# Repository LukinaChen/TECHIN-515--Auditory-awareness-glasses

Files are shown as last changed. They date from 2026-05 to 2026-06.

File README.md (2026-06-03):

# Auditory Awareness Glasses

Real-time wearable assistive glasses for deaf and hard-of-hearing users. The system detects, classifies, and localizes environmental sounds, then alerts the wearer through NeoPixel LEDs (visual) and haptic vibration motors (tactile) built into the glasses frame.

## Team

- **Lukina Chen** — Hardware lead, TDOA signal processing, PCB design (rear boards + main board)
- **Anuj Kamasamudram** — ML & software lead, YAMNet sound classification, front board PCB design
- **Yilu Huang** — Signal & firmware lead, GPIO alert dispatch timing, main board v2 design

## System Architecture

```
4× T5838 PDM Mics ──→ TXS0108 Level Shifter ──→ XIAO ESP32-S3
    (1.8V)              (1.8V ↔ 3.3V)              (3.3V)
                                                       │
                                    ┌──────────────────┤
                                    ▼                  ▼
                              3× NeoPixel LED    2× ERM Motor
                              (direction)        (rear alert)
```

All processing runs on-device with no internet connection. The ESP32-S3 captures audio from four PDM microphones, runs a quantized YAMNet model for sound classification, and uses TDOA (Time Difference of Arrival) across mic pairs for direction estimation.

| Layer | Technology |
|---|---|
| Sound classification | YAMNet (Google, 521 AudioSet classes), int8 quantized |
| Edge hardware | XIAO ESP32-S3 (8 MB flash + 8 MB PSRAM) |
| Microphones | 4× T5838 (MMICT5838-00-012) PDM MEMS, 1.8V |
| Visual output | 3× SK6812-MINI-E NeoPixel LEDs |
| Haptic output | 2× ERM coin vibration motors |
| Level shifting | TXS0108EPWR (TSSOP-20), 1.8V ↔ 3.3V |
| Power | LiPo battery → Xiao charger → XC6206P182MR-G 1.8V LDO |

## Sound → Alert Mapping

| Sound Category | LED Color | Motor |
|---|---|---|
| Silence | OFF | Off |
| Speech / Voice | Blue | Off |
| Music | Purple | Off |
| Alarm / Siren | Red | Both vibrate |
| Animal sounds | Yellow | Off |
| Door / Knock | Orange | Off |
| Horn / Beeping | Orange | Rear vibrate |
| Vehicle | White | Rear vibrate |
| Phone ringing | Purple | Off |
| Other | Green | Off |

LED color encodes the sound category. Motor vibration triggers only for rear-origin sounds, alerting the user to threats they cannot see.

## Direction Estimation (TDOA)

Four microphones are arranged in two pairs to estimate direction:

- **Front pair** (PCB1): 2× T5838 on the glasses front frame — left/right discrimination
- **Rear pair** (PCB5 or PCB2/3): 2× T5838 near the ears — front/back discrimination

The ESP32-S3 runs two I2S PDM interfaces. Cross-correlation between mic pairs yields a time delay that maps to an angle of arrival. Results from the TDOA test rig (breadboard prototype):

| Direction | Accuracy |
|---|---|
| Left / Right | 7/7 = 100% |
| Front | 3/3 = 100% |
| Back | 2/5 = 40% (breadboard contact issues) |

## Hardware: PCB Design

The system uses multiple PCBs connected by 0.5 mm pitch FPC cables.

### PCB1 — Front Board (Anuj)

Sits on the top of the glasses front frame (~60 mm long).

- 2× T5838 mic, 3× SK6812-MINI-E LED, XC6206 LDO, caps, WAKE combining diodes
- Connects to main board via 2× FH12 6-pin FPC

### PCB2 & PCB3 — Rear Boards (Lukina)

Sit at the ends of the glasses arms near the ears (~25 mm each). Same schematic, mirrored.

- 1× T5838 mic, 1× ERM motor, SI2302 MOSFET, 1N4148W diode, ferrite bead, 2× 100nF caps
- PCB2 mic SELECT → GND (left channel), PCB3 mic SELECT → 1V8 (right channel)
- Connects to main board via FH12 8-pin FPC
- Layout rule: mic at one end, motor at the other, separate GND pours with single-point join

### PCB4 — Main Board v1 (Lukina)

Central hub at the back of the head. Houses the MCU, level shifter, LDO, and all FPC connectors.

- U1: Xiao ESP32-S3 SMD, U2: XC6206 1.8V LDO, U3: TXS0108EPWR level shifter
- 4× FPC connectors (2× 6-pin for front board, 2× 8-pin for rear boards)
- JST PH 2-pin battery connector, PCM12SMTR SPDT switch
- Top side: Xiao + switch + battery connector. Bottom side: everything else.

### PCB5 — Main Board v2 (Yilu)

Combines PCB2, PCB3, and PCB4 into a single board. Rear mics and motor driver are integrated on-board. Connects to front board only via 2× 6-pin FPC.

Components: Xiao ESP32-S3 SMD, XC6206 LDO, TXS0108EPWR, 2× T5838 (MK3/MK4), SI2302 + 1N4148W motor driver, PCM12SMTR switch, JST PH battery connector.

## Firmware

### PlatformIO Configuration

```ini
[env:seeed_xiao_esp32s3]
platform = espressif32
board = seeed_xiao_esp32s3
framework = arduino
monitor_speed = 115200
build_flags = -DARDUINO_USB_CDC_ON_BOOT=1
```

### GPIO Pin Map (PCB5)

| GPIO | Xiao Pin | Function |
|---|---|---|
| GPIO1 | D0 | PDM_CLK (all mics clock) |
| GPIO2 | D1 | PDM_DATA (rear mics, through TXS0108) |
| GPIO3 | D2 | WAKE_JST_3V3 |
| GPIO4 | D3 | PDM_THSEL |
| GPIO5 | D4 | MTR_PWM (ERM motor via MOSFET) |
| GPIO6 | D5 | PDM_DATA_FRONT (front mics) |
| GPIO43 | D6 | LED_DATA (NeoPixel) |
| GPIO9 | Pin 11 | WAKE_M4_3V3 |

### I2S PDM Channel Mapping

ESP32-S3 I2S swaps left/right relative to the T5838 convention:

```cpp
// samples[i]   = Right channel (MK3, SELECT=1V8)
// samples[i+1] = Left channel  (MK4, SELECT=GND)
```

### Basic Mic Test Code

```cpp
#include <Arduino.h>
#include <driver/i2s.h>

#define I2S_WS   1   // PDM_CLK
#define I2S_DIN  2   // PDM_DATA
#define SAMPLE_RATE 16000
#define BUFFER_SIZE 512

int16_t samples[BUFFER_SIZE];

void setup() {
    Serial.begin(115200);
    delay(2000);

    i2s_config_t i2s_config = {
        .mode = (i2s_mode_t)(I2S_MODE_MASTER | I2S_MODE_RX | I2S_MODE_PDM),
        .sample_rate = SAMPLE_RATE,
        .bits_per_sample = I2S_BITS_PER_SAMPLE_16BIT,
        .channel_format = I2S_CHANNEL_FMT_RIGHT_LEFT,
        .communication_format = I2S_COMM_FORMAT_STAND_I2S,
        .intr_alloc_flags = ESP_INTR_FLAG_LEVEL1,
        .dma_buf_count = 4,
        .dma_buf_len = BUFFER_SIZE,
    };

    i2s_pin_config_t pin_config = {
        .bck_io_num = I2S_PIN_NO_CHANGE,
        .ws_io_num = I2S_WS,
        .data_out_num = I2S_PIN_NO_CHANGE,
        .data_in_num = I2S_DIN,
    };

    i2s_driver_install(I2S_NUM_0, &i2s_config, 0, NULL);
    i2s_set_pin(I2S_NUM_0, &pin_config);
}

void loop() {
    size_t bytes_read;
    i2s_read(I2S_NUM_0, samples, sizeof(samples), &bytes_read, portMAX_DELAY);

    int num = bytes_read / sizeof(int16_t);
    int16_t min_l = 32767, max_l = -32768;
    int16_t min_r = 32767, max_r = -32768;

    for (int i = 0; i < num; i += 2) {
        if (samples[i] > max_r) max_r = samples[i];
        if (samples[i] < min_r) min_r = samples[i];
        if (samples[i+1] > max_l) max_l = samples[i+1];
        if (samples[i+1] < min_l) min_l = samples[i+1];
    }

    Serial.printf("L[%d,%d] Range:%d | R[%d,%d] Range:%d\n",
                  min_l, max_l, max_l - min_l,
                  min_r, max_r, max_r - min_r);
    delay(200);
}
```

Expected signal levels:

| State | Range |
|---|---|
| Quiet room | 5,000 – 15,000 |
| Normal speech | 30,000 – 65,535 |
| Loud clap | 50,000 – 65,535 |
| Data line disconnected | Fixed at -30,935 |

## ML Pipeline (Laptop Prototyping)

The ML pipeline runs on a laptop for prototyping. In production, the quantized model runs directly on the ESP32-S3.

### Repository Layout

```
DetectionGlasses/
└── YamnetTest/
    ├── yamnet_mic_test.py            # Live mic classification (no hardware)
    ├── yamnet_esp32_feasibility.py   # TFLite conversion + ESP32 feasibility report
    ├── yamnet_serial.py              # Laptop → USB serial → XIAO NeoPixel bridge
    ├── yamnet_accuracy_test.py       # float32 vs int8 accuracy on ESC-50
    ├── yamnet_urbansound_test.py     # Accuracy on UrbanSound8K
    ├── neopixel_noise_test/
    │   └── neopixel_noise_test.ino   # Arduino NeoPixel LED control sketch
    └── tflite_models/
        ├── yamnet_full.tflite        # ~3.7 MB float32
        ├── yamnet_int8.tflite        # ~0.9 MB int8 quantized (ESP32 target)
        └── yamnet_saved_model/
```

### Quick Start

```bash
# Live mic demo (laptop only, no hardware)
pip install tensorflow tensorflow-hub sounddevice numpy scipy
python YamnetTest/yamnet_mic_test.py

# Generate TFLite models + ESP32 feasibility report
pip install tensorflow tensorflow-hub numpy
python YamnetTest/yamnet_esp32_feasibility.py

# Serial bridge (laptop mic → USB → XIAO NeoPixels)
pip install tensorflow tensorflow-hub sounddevice numpy pyserial
python YamnetTest/yamnet_serial.py --port /dev/cu.usbmodem1101

# Accuracy benchmarks
pip install tensorflow tensorflow-hub numpy scipy soundfile librosa tqdm
python YamnetTest/yamnet_accuracy_test.py --esc50-dir YamnetTest/downloads/ESC-50-master
python YamnetTest/yamnet_urbansound_test.py --limit 200
```

### Serial Protocol

```
C:speech:0.92:180    # category, confidence, brightness (0-255)
B:180                # brightness-only update
T:0.50               # set confidence threshold
OFF                  # turn LEDs off
```

### ESP32-S3 Model Feasibility

| Resource | Requirement | ESP32-S3 (N8R8) | Status |
|---|---|---|---|
| Flash | ~0.9 MB (int8) | 8 MB | ✅ |
| RAM (activations) | ~300–400 KB | 8 MB PSRAM | ✅ |
| Inference time | ~200 ms target | TBD | — |

## Known Issues

- **TXS0108 OE wiring bug (PCB5):** R1 was routed to 3V3 instead of 1V8. OE max is VCCA+0.5V = 2.3V. Fixed with fly wire. Must be corrected in next revision.
- **MK3 weak signal (PCB5):** Right-channel mic produces very low Range (~100 vs expected ~10,000). Likely a soldering defect. Needs resolder or replacement.
- **FPC intermittent contact (PCB3):** Data line drops to fixed -30,935 value. Caused by loose FPC cable or connector lock. Resolved by reinserting and locking FPC.
- **ESP32 USB boot issue:** After uploading certain code, USB CDC may fail to initialize. Fix: double-click RESET to enter bootloader, then immediately upload.

## Bill of Materials

| Component | Part Number | Qty | Notes |
|---|---|-----|---|
| MCU | XIAO ESP32-S3 SMD | 1 | Castellated pads |
| Microphone | MMICT5838-00-012 (T5838) | 4 | PDM MEMS, 1.8V |
| Level shifter | TXS0108EPWR | 1 | TSSOP-20, 1.8V ↔ 3.3V |
| 1.8V LDO | XC6206P182MR-G | 1 | SOT-23 |
| NeoPixel LED | SK6812-MINI-E | 3 | RGB addressable |
| ERM motor | 10mm coin type | 2 | Vibration haptic |
| MOSFET | SI2302 | 1–2 | SOT-23, motor switch |
| Flyback diode | 1N4148W | 1–2 | SOD-323 |
| Ferrite bead | 600Ω 0402 | 1–2 | Motor power filtering |
| FPC connector (6-pin) | FH12-6S-0.5SH | 2–4 | Front board connection |
| FPC connector (8-pin) | FH12-8S-0.5SH | 2 | Rear board connection |
| Battery connector | JST PH 2-pin | 1 | LiPo battery |
| Switch | PCM12SMTR | 1 | SPDT SMD |
| Battery | LiPo 500–1000 mAh | 1 | 3.7V nominal |

## GitHub

[https://github.com/LukinaChen/TECHIN-515--Auditory-awareness-glasses](https://github.com/LukinaChen/TECHIN-515--Auditory-awareness-glasses)

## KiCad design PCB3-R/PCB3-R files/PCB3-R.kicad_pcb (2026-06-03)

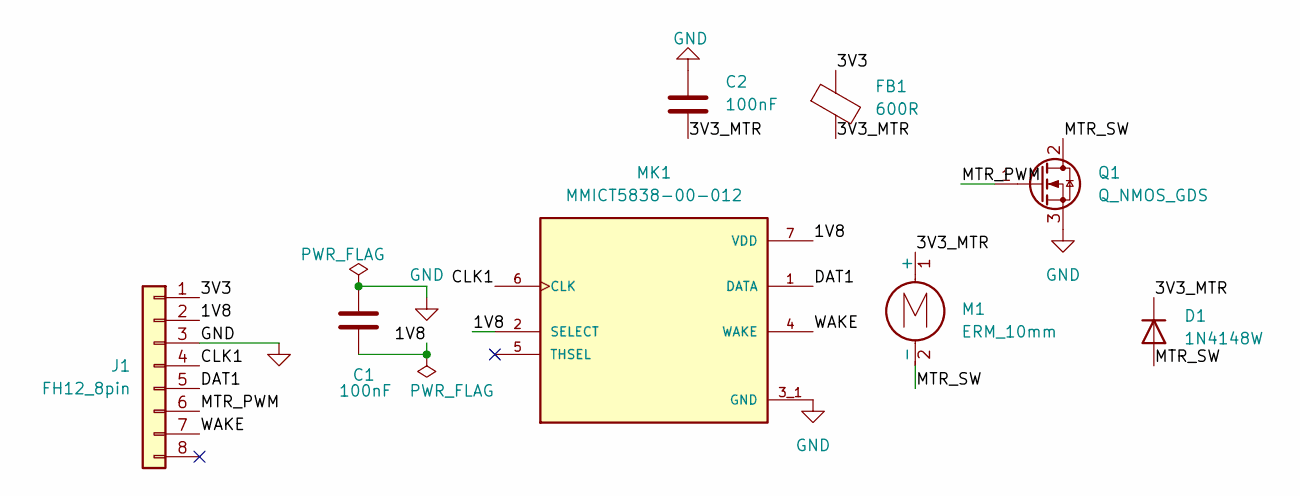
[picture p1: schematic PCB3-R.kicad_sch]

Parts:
C1, C2: 100nF; C_0402_1005Metric
D1: 1N4148W; D_SOD-323
FB1: 600R; L_0402_1005Metric
J1: FH12_8pin; Hirose_FH12-8S-0.5SH_1x08-1MP_P0.50mm_Horizontal
M1: ERM_10mm; PinHeader_1x02_P2.54mm_Vertical
MK1: MMICT5838-00-012; MIC_MMICT5838-00-012; PARTREV 1.1
Q1: Q_NMOS_GDS; SOT-23

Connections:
/1V8: C1.2, J1.2, MK1.2 (SELECT), MK1.7 (VDD)
/3V3: FB1.1, J1.1
/3V3_MTR: C2.2, D1.1 (K), FB1.2, M1.1 (+)
/CLK1: J1.4, MK1.6 (CLK)
/DAT1: J1.5, MK1.1 (DATA)
/MTR_PWM: J1.6, Q1.1 (G)
/MTR_SW: D1.2 (A), M1.2 (-), Q1.2 (D)
/WAKE: J1.7, MK1.4 (WAKE)
GND: C1.1, C2.1, J1.3, MK1.3_1 (GND), MK1.3_2 (GND), Q1.3 (S)

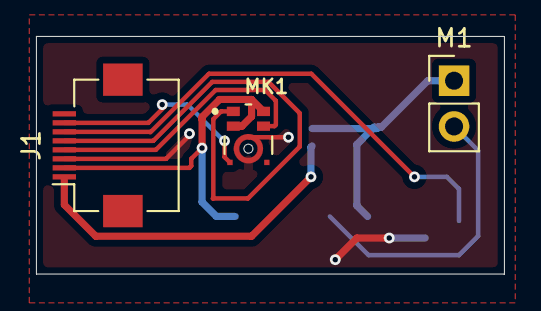
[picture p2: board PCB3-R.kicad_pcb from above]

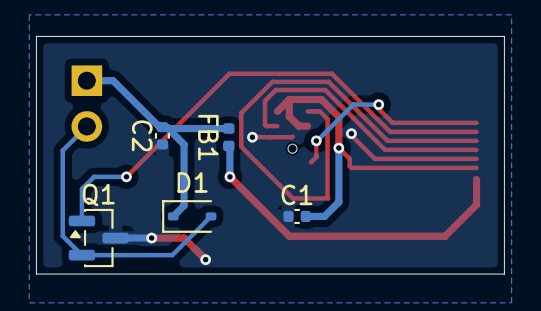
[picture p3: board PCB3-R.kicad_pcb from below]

Board: 2 copper layers, 26.0 x 13.2 mm, 8 parts (5 on the bottom side), 9 nets.

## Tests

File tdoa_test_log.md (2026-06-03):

# Project Handoff Summary — Auditory Awareness Glasses (Updated)

## Project Overview
Wearable assistive glasses for deaf/hard-of-hearing users. Detects, classifies, and localizes environmental sounds in real time. Alerts user through LED bar (visual) and haptic vibration motors (tactile) built into glasses frame.

---

## Team & Roles
- **Lukina Chen (you)** — Hardware lead, TDOA signal processing, PCB design for rear boards + main board
- **Anuj Kamasamudram** — ML & software lead, YAMNet sound classification, PCB1 (front board) design
- **Yilu Huang** — Signal & firmware lead, GPIO alert dispatch timing, designed PCB5 (main board v2)

---

## System Architecture
- **MCU:** Xiao ESP32-S3 (SMD version)
- **Mics:** 4× T5838 (MMICT5838-00-012) PDM MEMS microphones, 1.8V supply
- **Output:** 3× SK6812-MINI-E NeoPixel LEDs + 2× ERM coin motors
- **Power:** LiPo battery → Xiao (built-in charger + 3.3V LDO) → XC6206P182MR-G (1.8V LDO for mics)
- **Level shifter:** TXS0108EPWR (TSSOP-20) — 1.8V ↔ 3.3V conversion for all mic signals
- **No internet connection** — all processing on-device

---

## PCB Status Summary

### PCB2 & PCB3 (Rear Boards - Lukina's design)
- Schematic: ✅ Done
- PCB layout: ✅ Done
- DRC: ✅ Pass
- Gerber: ✅ Exported
- **PCB3 (Right) Testing:**
  - Mic: ✅ Confirmed working (tested with breakout board + ESP32-S3 on breadboard)
  - ERM motor: ✅ Confirmed working (controlled via MOSFET, GPIO must be pulled LOW to stop motor)
  - FPC connection: ⚠️ Intermittent contact issues (34601 fixed value when FPC disconnects)

### PCB4 (Main Board - Lukina's design)
- Schematic: ✅ Done
- PCB layout: ✅ Done
- DRC status:
  - 1 excluded error: B.Cu GND zone missing connection (ignorable — GND pads connected via F.Cu)
  - Remaining warnings: silkscreen clipping (ignorable)
  - Dangling track warnings: cleaned up (PDM_DAT1, MTR_PWM_R, 1V8, PDM_CLK1_1V8)
- Mounting holes: ✅ Added (4× MountingHole_2.1mm at corners)
- Board outline: ✅ Fixed (Edge.Cuts gap closed)
- **Not yet fabricated or assembled**

### PCB5 (Main Board v2 - Yilu's design, combines PCB2/3 + main)
- Schematic: ✅ Done
- PCB fabricated: ✅ Done
- Components soldered: ✅ Done
- **Testing results:**
  - Power: ✅ 3.3V and 1.8V confirmed correct
  - TXS0108 level shifter: ✅ Working (after OE fix)
  - MK4 mic (SELECT=GND, Left channel): ✅ Working — Range ~10000 quiet, 50000+ clap
  - MK3 mic (SELECT=1V8, Right channel): ❌ Very weak signal — Range ~100 quiet, ~5000 speaking
  - ERM motor: Not yet tested on PCB5
  - Front PCB connection: Not yet tested

### PCB1 (Front Board - Anuj's design)
- Not yet tested with main board

---

## Critical Bugs Found & Fixed

### 1. TXS0108 OE voltage error (PCB5)
- **Problem:** R1 (11kΩ) connected OE to 3V3 instead of 1V8
- **Impact:** OE max voltage is VCCA+0.5V = 2.3V, 3.3V exceeded limit
- **Fix:** Removed R1, flew wire from OE (Pin 10) to LDO VOUT (1.8V) with R1 in series
- **Status:** ✅ Fixed, OE now reads 1.8V

### 2. TXS0108 Pin 18 virtual solder (PCB5)
- **Problem:** Pin 18 (PDM_DATA B-side) had cold solder joint, ESP32 D1 read 0.2V instead of ~1.5V
- **Impact:** Neither MK3 nor MK4 data could reach ESP32
- **Fix:** Re-soldered Pin 18
- **Status:** ✅ Fixed, MK4 now works

### 3. MK3 weak signal (PCB5)
- **Problem:** MK3 Range only ~100 (should be ~10000), very weak response to sound
- **Likely cause:** MK3 soldering issue (VDD or DATA pad)
- **Status:** ❌ Unresolved — MK3 was removed for standalone testing, needs to be soldered back or replaced

---

## ESP32 I2S PDM Important Notes

### Channel swap
ESP32 I2S channels are swapped from T5838 convention:
- `samples[i]` = **Right channel** (MK3, SELECT=1V8)
- `samples[i+1]` = **Left channel** (MK4, SELECT=GND)

### Working I2S configuration (PCB5)
```cpp
#define I2S_WS   1   // PDM_CLK → GPIO1 (D0)
#define I2S_DIN  2   // PDM_DATA → GPIO2 (D1)

i2s_config_t i2s_config = {
    .mode = (i2s_mode_t)(I2S_MODE_MASTER | I2S_MODE_RX | I2S_MODE_PDM),
    .sample_rate = 16000,
    .bits_per_sample = I2S_BITS_PER_SAMPLE_16BIT,
    .channel_format = I2S_CHANNEL_FMT_RIGHT_LEFT,
};
```

### T5838 supply voltage
- Design voltage: 1.8V (for power saving and TXS0108 compatibility)
- Testing: Works at 3.3V (VDD range 1.6V–3.6V), but noise floor is higher
- PCB3 standalone testing used 3.3V on both VDD and 1V8 pins

### Signal levels (normal operation)
| State | Expected Range |
|---|---|
| Quiet | 5000–15000 |
| Speaking | 30000–65535 |
| Clap | 50000–65535 |

### Common failure mode
- `-30935` fixed value = **data line disconnected** (FPC contact, virtual solder, or mic not present)

---

## PCB5 GPIO Pin Assignment (Yilu's design)

| GPIO | Xiao Pin | Function |
|---|---|---|
| GPIO1 | D0 | PDM_CLK (all mics clock) |
| GPIO2 | D1 | PDM_DATA (rear mics data, through TXS0108) |
| GPIO3 | D2 | WAKE_JST_3V3 |
| GPIO4 | D3 | PDM_THSEL |
| GPIO5 | D4 | MTR_PWM (ERM motor via MOSFET) |
| GPIO6 | D5 | PDM_DATA_FRONT (front mics data) |
| GPIO43 | D6 | LED_DATA (NeoPixel) |
| GPIO9 | Pin 11 | WAKE_M4_3V3 |

## TXS0108 Pin Map (PCB5)

| Physical Pin | Function | Side |
|---|---|---|
| 1 | CLK net (A1) | 1.8V |
| 2 | VCCA (+1V8) | Power |
| 3 | DATA_BACK net (A2) | 1.8V |
| 4 | DATA_FRONT net (A3) | 1.8V |
| 5 | WAKE_JST_1V8 (A4) | 1.8V |
| 6 | THSEL net (A5) | 1.8V |
| 7 | WAKE_M4_1V8 (A6) | 1.8V |
| 8 | GND (A7) | — |
| 9 | GND (A8) | — |
| 10 | OE | Enable (→1V8 via R1) |
| 11 | GND | — |
| 12 | GND | — |
| 13 | GND (B7) | — |
| 14 | WAKE_M4_3V3 (B6) | 3.3V |
| 15 | PDM_THSEL (B5) | 3.3V |
| 16 | WAKE_JST_3V3 (B4) | 3.3V |
| 17 | PDM_DATA_FRONT (B3) | 3.3V |
| 18 | PDM_DATA (B2) | 3.3V |
| 19 | VCCB (Net-U1-3V3) | Power |
| 20 | PDM_CLK (B1) | 3.3V |

---

## PCB5 BOM

| Reference | Qty | Value | Footprint |
|---|-----|---|---|
| Batteryconnector1 | 1 | S2B-PH-K-SLFSN | JST PH 2-pin |
| C1,C6,C7 | 3 | 2.2μF | 0603 |
| C2,C3,C4,C5,C8,C9 | 6 | 680nF | 0603 |
| D1 | 1 | Diode | SOD-123 |
| FB1 | 1 | Ferrite Bead | 0402 |
| J1_Right1 | 1 | FPC 6-pin (Right) | FH12-6S-0.5SH |
| J2_Left1 | 1 | FPC 6-pin (Left) | FH12-6S-0.5SH |
| J3 | 1 | ERM coin motor | Pin Header 2-pin |
| MK3, MK4 | 2 | MMICT5838-00-012 | T5838 |
| Q1 | 1 | SI2302 | SOT-23 |
| R1 | 1 | 11kΩ | 0603 |
| SW2 | 1 | PCM12SMTR | SPDT SMD |
| U1 | 1 | XIAO-ESP32-S3-SMD | Castellated SMD |
| U2 | 1 | XC6206P182MR-G | SOT-23 (1.8V LDO) |
| U3 | 1 | TXS0108EPWR | TSSOP-20 |

---

## FPC Connector Pin Definitions (PCB5)

### J2_Left1 (6-pin, to front board)
1. DATA_FRONT net
2. CLK net
3. THSEL net
4. WAKE_JST_1V8
5. NC
6. NC

### J1_Right1 (6-pin, to front board)
1. NC
2. +1V8
3. GND
4. LED_DATA
5. NC
6. NC

---

## What Needs to Be Done Next

1. ❌ Fix MK3 on PCB5 — resolder or replace with new T5838
2. ❌ Test ERM motor on PCB5 (use Serial command 'm'/'s')
3. ❌ Test front PCB (PCB1) connected to PCB5 via FPC
4. ❌ Test LED output
5. ❌ Full system integration test (all 4 mics + LED + motor)
6. ❌ Battery power test
7. ✅ PCB4 (Lukina's main board) — DRC clean, ready for Gerber export if needed as backup

---

## Items Already Purchased
- MMICT5838-00-012 × 5
- ESP32-S3 × 2
- FH12-6S-0.5SH (6-pin) × 6
- XC6206P182MR-G × 6
- INMP441 (testing) × 8
- SPH0645 (testing) × 4
- TXS0108EPWR × 2 (1 used on PCB5, 1 spare)
- FH12-8S-0.5SH (8-pin) × 5
- FPC cable 8-pin 0.5mm × 3
- FPC cable 6-pin 0.5mm × 3
- SI2302 MOSFET SOT-23 × 4
- 1N4148W SOD-323 × 4
- Ferrite bead 600Ω 0402 × 4
- Capacitors (0402 and 0603)
- ERM coin motor 10mm × 2
- SPDT switch × 2
- JST PH 2-pin × 1
- PCM12SMTR from DigiKey

## Still Need
- LiPo battery 500-1000mAh × 1
- Replacement T5838 for MK3 (if current one is damaged)

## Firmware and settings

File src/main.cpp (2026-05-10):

/*
 * 4-Mic TDOA + Motor + LED Alert System
 * Board: Xiao ESP32-S3
 * 
 * I2S0 (front pair):
 *   SCK → GPIO7 (D8), WS → GPIO8 (D9), SD → GPIO9 (D10)
 *   Mic1 L/R → GND (front left), Mic2 L/R → 3.3V (front right)
 *
 * I2S1 (rear pair):
 *   SCK → GPIO1 (D0), WS → GPIO2 (D1), SD → GPIO3 (D2)
 *   Mic3 L/R → GND (rear left), Mic4 L/R → 3.3V (rear right)
 *
 * Motor (via S8050 NPN + 1kΩ + 1N4148):
 *   Left motor  → GPIO4 (D3)
 *   Right motor → GPIO6 (D5)
 *
 * NeoPixel LED:
 *   DIN → GPIO5 (D4), VDD → 3.3V, GND → GND
 */

#include <Arduino.h>
#include <driver/i2s.h>
#include <Adafruit_NeoPixel.h>

// ----- I2S0 Pins (front pair) -----
#define I2S0_SCK  7
#define I2S0_WS   8
#define I2S0_SD   9

// ----- I2S1 Pins (rear pair) -----
#define I2S1_SCK  1
#define I2S1_WS   2
#define I2S1_SD   3

// ----- Motor Pins -----
#define MTR_LEFT  4   // GPIO4 (D3)
#define MTR_RIGHT 6   // GPIO6 (D5)

// ----- NeoPixel LED -----
#define LED_PIN   5   // GPIO5 (D4)
#define LED_COUNT 1
Adafruit_NeoPixel led(LED_COUNT, LED_PIN, NEO_GRB + NEO_KHZ800);

// ----- Audio Settings -----
#define SAMPLE_RATE     44100
#define BUFFER_LEN      512
#define CAPTURE_SAMPLES 1200
#define MAX_DELAY       20
#define CLAP_THRESHOLD  15000
#define COOLDOWN_MS     800
#define ALERT_DURATION  500  // motor vibrate + LED on for 1 second

// ----- Buffers -----
int32_t raw_i2s0[BUFFER_LEN];
int32_t raw_i2s1[BUFFER_LEN];

int32_t front_left[CAPTURE_SAMPLES];
int32_t front_right[CAPTURE_SAMPLES];
int32_t rear_left[CAPTURE_SAMPLES];
int32_t rear_right[CAPTURE_SAMPLES];

int capture_index = 0;
bool capturing = false;
bool ready_to_analyze = false;
int trial_number = 0;
unsigned long last_trigger_time = 0;
unsigned long alert_start_time = 0;
bool alerting = false;

void setup_i2s(i2s_port_t port, int sck, int ws, int sd) {
  i2s_config_t config = {
    .mode = (i2s_mode_t)(I2S_MODE_MASTER | I2S_MODE_RX),
    .sample_rate = SAMPLE_RATE,
    .bits_per_sample = I2S_BITS_PER_SAMPLE_32BIT,
    .channel_format = I2S_CHANNEL_FMT_RIGHT_LEFT,
    .communication_format = I2S_COMM_FORMAT_STAND_I2S,
    .intr_alloc_flags = ESP_INTR_FLAG_LEVEL1,
    .dma_buf_count = 8,
    .dma_buf_len = BUFFER_LEN,
    .use_apll = false,
    .tx_desc_auto_clear = false,
    .fixed_mclk = 0
  };

  i2s_pin_config_t pins = {
    .bck_io_num   = sck,
    .ws_io_num    = ws,
    .data_out_num = I2S_PIN_NO_CHANGE,
    .data_in_num  = sd
  };

  i2s_driver_install(port, &config, 0, NULL);
  i2s_set_pin(port, &pins);
  i2s_zero_dma_buffer(port);
}

void setup() {
  Serial.begin(115200);
  delay(2000);

  // Setup motors
  pinMode(MTR_LEFT, OUTPUT);
  pinMode(MTR_RIGHT, OUTPUT);
  digitalWrite(MTR_LEFT, LOW);
  digitalWrite(MTR_RIGHT, LOW);

  // Setup NeoPixel
  led.begin();
  led.clear();
  led.show();

  // Setup I2S
  setup_i2s(I2S_NUM_0, I2S0_SCK, I2S0_WS, I2S0_SD);
  setup_i2s(I2S_NUM_1, I2S1_SCK, I2S1_WS, I2S1_SD);

  delay(500);

  Serial.println("==========================================");
  Serial.println("  4-Mic TDOA + Motor + LED Alert");
  Serial.println("  Left motor:  GPIO4 (D3)");
  Serial.println("  Right motor: GPIO6 (D5)");
  Serial.println("  NeoPixel:    GPIO5 (D4)");
  Serial.println("==========================================");
  Serial.println("Ready! Clap to test direction + alert.");
  Serial.println("------------------------------------------");
}

void remove_dc(int32_t* buf, int len) {
  int64_t sum = 0;
  for (int i = 0; i < len; i++) sum += buf[i];
  int32_t dc = sum / len;
  for (int i = 0; i < len; i++) buf[i] -= dc;
}

int compute_tdoa(int32_t* buf_a, int32_t* buf_b) {
  remove_dc(buf_a, CAPTURE_SAMPLES);
  remove_dc(buf_b, CAPTURE_SAMPLES);

  float max_corr = 0;
  int best_delay = 0;

  for (int d = -MAX_DELAY; d <= MAX_DELAY; d++) {
    float corr = 0;
    int count = 0;
    for (int i = 0; i < CAPTURE_SAMPLES; i++) {
      int j = i + d;
      if (j >= 0 && j < CAPTURE_SAMPLES) {
        corr += (float)buf_a[i] * (float)buf_b[j];
        count++;
      }
    }
    if (count > 0) corr /= count;
    if (corr > max_corr) {
      max_corr = corr;
      best_delay = d;
    }
  }
  return best_delay;
}

void trigger_alert(const char* lr_dir, const char* fr_dir) {
  // LED color based on left/right direction
  if (strcmp(lr_dir, "LEFT") == 0) {
    led.setPixelColor(0, led.Color(0, 0, 255));    // Blue = left
    Serial.println("  [LED] Blue (left)");
  } else if (strcmp(lr_dir, "RIGHT") == 0) {
    led.setPixelColor(0, led.Color(0, 255, 0));    // Green = right
    Serial.println("  [LED] Green (right)");
  } else {
    led.setPixelColor(0, led.Color(255, 255, 255)); // White = center
    Serial.println("  [LED] White (center)");
  }
  led.show();

  // Motor only vibrates for BACK sounds
  if (strcmp(fr_dir, "BACK") == 0) {
    if (strcmp(lr_dir, "LEFT") == 0) {
      digitalWrite(MTR_LEFT, HIGH);
      digitalWrite(MTR_RIGHT, LOW);
      Serial.println("  [MOTOR] Left vibrate (back-left)");
    } else if (strcmp(lr_dir, "RIGHT") == 0) {
      digitalWrite(MTR_LEFT, LOW);
      digitalWrite(MTR_RIGHT, HIGH);
      Serial.println("  [MOTOR] Right vibrate (back-right)");
    } else {
      digitalWrite(MTR_LEFT, HIGH);
      digitalWrite(MTR_RIGHT, HIGH);
      Serial.println("  [MOTOR] Both vibrate (back-center)");
    }
  } else {
    digitalWrite(MTR_LEFT, LOW);
    digitalWrite(MTR_RIGHT, LOW);
    Serial.println("  [MOTOR] Off (front/middle)");
  }

  alerting = true;
  alert_start_time = millis();
} 


void stop_alert() {
  digitalWrite(MTR_LEFT, LOW);
  digitalWrite(MTR_RIGHT, LOW);
  led.clear();
  led.show();
  alerting = false;
}

void analyze_direction() {
  // Left-Right: average of front pair AND rear pair
  int lr_delay_front = compute_tdoa(front_left, front_right);
  int lr_delay_rear = compute_tdoa(rear_left, rear_right);
  int lr_delay = (lr_delay_front + lr_delay_rear) / 2;

  // Front-Back: average of left side AND right side
  int fb_delay_left = compute_tdoa(front_left, rear_left);
  int fb_delay_right = compute_tdoa(front_right, rear_right);
  int fb_delay = (fb_delay_left + fb_delay_right) / 2;

  float lr_us = (float)lr_delay / SAMPLE_RATE * 1000000.0;
  float fb_us = (float)fb_delay / SAMPLE_RATE * 1000000.0;

  const char* lr_dir;
  if (lr_delay > 3) lr_dir = "RIGHT";
  else if (lr_delay < -3) lr_dir = "LEFT";
  else lr_dir = "CENTER";

  const char* fr_dir;
if (fb_delay > 5) fr_dir = "FRONT";
else if (fb_delay < -5) fr_dir = "BACK";
else fr_dir = "FRONT";  // default to FRONT (no motor) 

  trial_number++;

  Serial.println("==========================================");
  Serial.printf("  Trial #%d\n", trial_number);
  Serial.println("  ---- Left/Right ----");
  Serial.printf("  Front pair delay: %d, Rear pair delay: %d\n", lr_delay_front, lr_delay_rear);
  Serial.printf("  Average delay: %d samples (%.1f us)\n", lr_delay, lr_us);
  Serial.printf("  Direction: %s\n", lr_dir);
  Serial.println("  ---- Front/Back ----");
  Serial.printf("  Left side delay: %d, Right side delay: %d\n", fb_delay_left, fb_delay_right);
  Serial.printf("  Average delay: %d samples (%.1f us)\n", fb_delay, fb_us);
  Serial.printf("  Direction: %s\n", fr_dir);
  Serial.println("  ---- Combined ----");
  Serial.printf("  >>> %s - %s <<<\n", fr_dir, lr_dir);

  trigger_alert(lr_dir, fr_dir);

  Serial.println("==========================================");
}

void loop() {
  // Turn off alert after duration
  if (alerting && (millis() - alert_start_time > ALERT_DURATION)) {
    stop_alert();
    Serial.println("Ready for next clap...");
  }

  size_t bytes_read_0 = 0;
  size_t bytes_read_1 = 0;

  i2s_read(I2S_NUM_0, raw_i2s0, sizeof(raw_i2s0), &bytes_read_0, portMAX_DELAY);
  i2s_read(I2S_NUM_1, raw_i2s1, sizeof(raw_i2s1), &bytes_read_1, portMAX_DELAY);

  int samples_0 = bytes_read_0 / sizeof(int32_t);
  int samples_1 = bytes_read_1 / sizeof(int32_t);

  for (int i = 0; i < samples_0; i += 2) {
    // Front pair — swapped to match ESP32 I2S channel mapping
    int32_t fl = raw_i2s0[i + 1] >> 14;  // front left  (L/R → GND)
    int32_t fr = raw_i2s0[i] >> 14;      // front right (L/R → 3.3V)

    int32_t rl = 0, rr = 0;
    if (i < samples_1) {
      rl = raw_i2s1[i + 1] >> 14;        // rear left   (L/R → GND)
      rr = raw_i2s1[i] >> 14;            // rear right  (L/R → 3.3V)
    }

    // Check for loud sound to trigger capture
    if (!capturing && !ready_to_analyze && !alerting) {
      if ((abs(fl) > CLAP_THRESHOLD || abs(fr) > CLAP_THRESHOLD ||
           abs(rl) > CLAP_THRESHOLD || abs(rr) > CLAP_THRESHOLD) &&
          (millis() - last_trigger_time > COOLDOWN_MS)) {
        capturing = true;
        capture_index = 0;
        last_trigger_time = millis();
        Serial.println("CLAP detected! Capturing from all 4 mics...");
      }
    }

    // Capture samples from all 4 mics
    if (capturing) {
      if (capture_index < CAPTURE_SAMPLES) {
        front_left[capture_index] = fl;
        front_right[capture_index] = fr;
        rear_left[capture_index] = rl;
        rear_right[capture_index] = rr;
        capture_index++;
      } else {
        capturing = false;
        ready_to_analyze = true;
      }
    }
  }

  if (ready_to_analyze) {
    analyze_direction();
    ready_to_analyze = false;
  }
}

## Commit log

2026-04-30 update test log: 4-mic results, motor+LED integration
2026-06-03 Revise TDOA Test Log and Project Summary
    Updated project title and overview, added team roles, and revised hardware specs. Documented critical bugs found and fixed during TDOA tests, along with detailed results and next steps for PCB design.
2026-06-03 Create PCB
